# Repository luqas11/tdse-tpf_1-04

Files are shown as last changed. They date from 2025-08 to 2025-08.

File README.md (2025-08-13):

# Proyecto Final
Este proyecto es el diseño de software y hardware para un **sistema de control de una máquina expendedora de bebidas**, proyecto final de la materia Taller de Sistemas Embebidos de la FIUBA.

## Notas
Para depurar el proyecto, se deben realizar las siguientes configuraciones en el STM32CubeIDE:
1. Run -> Debug configurations -> Debugger -> Debug Probe -> ST-LINK (OpenOCD) -> Apply
2. Run -> Debug configurations -> Debugger -> Show generator options -> Reset Mode -> Software system reset -> Apply
3. Run -> Debug configurations -> Startup -> Initialization Commands -> Escribir `monitor arm semihosting enable` -> Apply

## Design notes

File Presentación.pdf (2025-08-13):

# Proyecto Final

MÁQUINA EXPENDEDORA DE BEBIDAS.

Taller de Sistemas Embebidos. Primer Cuatrimestre de 2025.

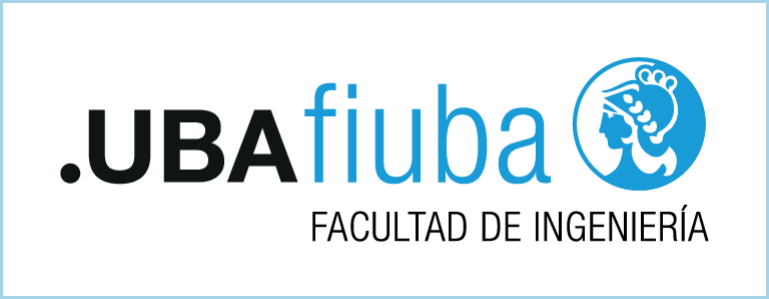
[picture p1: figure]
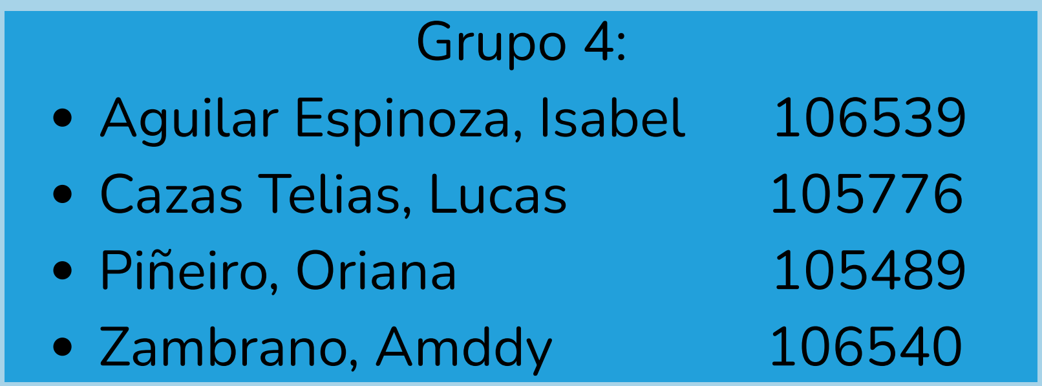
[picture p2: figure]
Grupo 4:; Aguilar Espinoza, Isabel; Cazas Telias, Lucas; Piñeiro, Oriana; Zambrano, Amddy

# Introducción al Proyecto

Este proyecto se centra en el diseño y la construcción de un prototipo para una máquina expendedora de bebidas. El sistema está gobernado por una placa de desarrollo NUCLEO-F103RB y cuenta con una interfaz de usuario que incluye una pantalla LCD y botones para la selección e interacción.

## Características Principales:

Controlador: Placa NUCLEO-F103RB
Interfaz de Usuario: Pantalla LCD y botones.
Funcionalidades:
Modo Cliente: Selección de 4 bebidas.
Modo Configuración: Gestión de precios y stock.

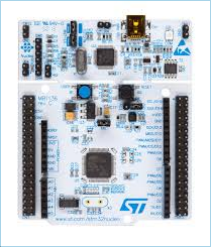
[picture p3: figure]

Detección de monedas (simulada mediante un botón). Indicador de estado a través de un LED RGB.

# Arquitectura del Hardware

La placa NUCLEO-F103RB funciona como la unidad de control principal del sistema, gestionando la interconexión con los diversos componentes periféricos para la operación de la máquina expendedora.

## Componentes Claves:

Placa NUCLEO-F103RB: Encargado de procesar la lógica de la máquina.
Display LCD (16x2): Proporciona información al usuario, como la bebida seleccionada, el precio y los estados de la máquina.

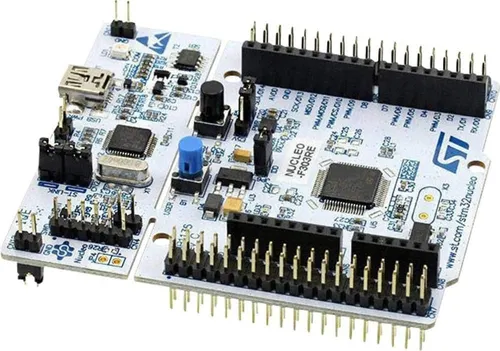
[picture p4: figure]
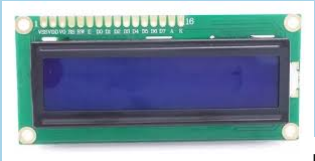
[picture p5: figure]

LED RGB: Ofrece una indicación visual del estado del sistema (Entrega de la bebida seleccionada).
Botones: Permiten la interacción del usuario (cliente y técnico) para navegar por los menús, seleccionar bebidas y confirmar acciones.
Sensor de Temperatura (LM35): Monitorea la temperatura de refrigeración de las bebidas. En caso de que la temperatura no sea la adecuada, el sistema entra en modo error.
Sensor de Monedas: Se simula a través de un botón (COIN) para registrar el ingreso de crédito.

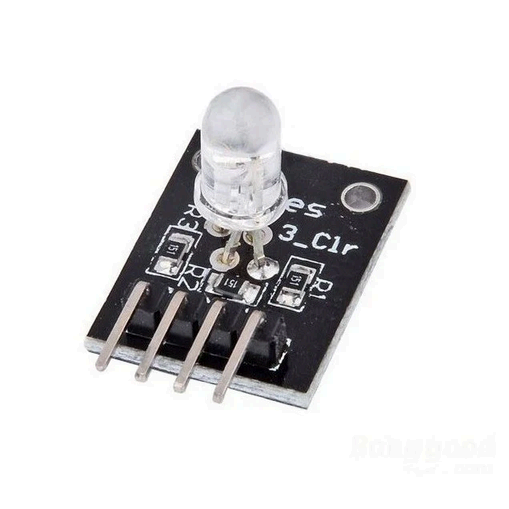
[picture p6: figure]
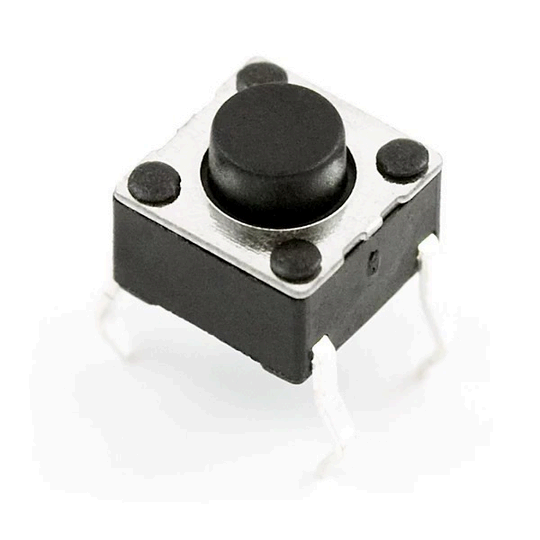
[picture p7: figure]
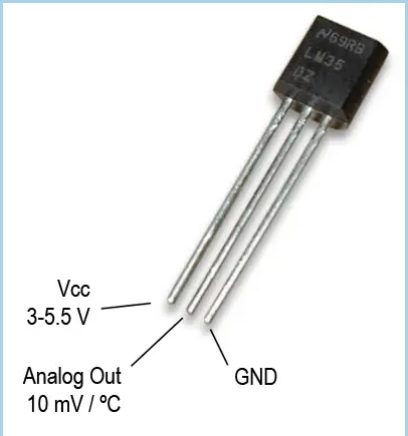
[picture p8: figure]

# Diagrama de Conexiones (Pinout)

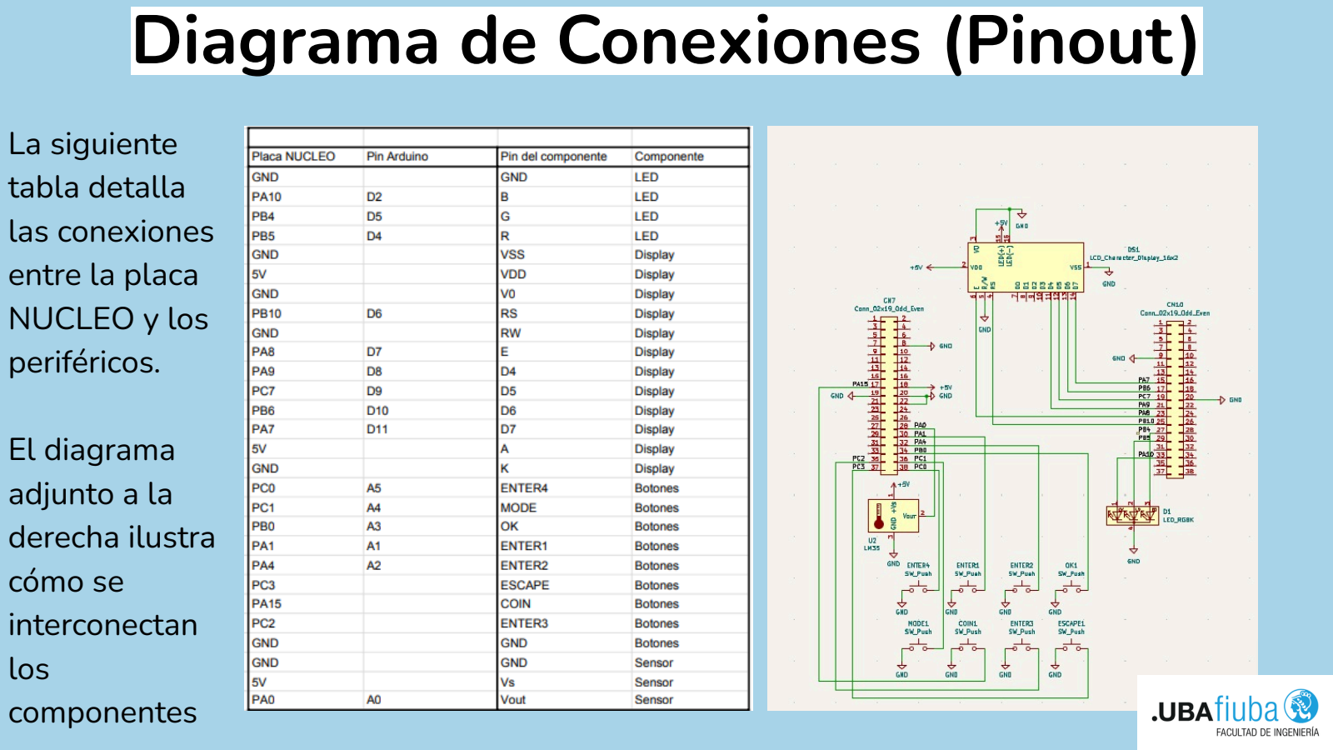
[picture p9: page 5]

La siguiente
tabla detalla
las conexiones
entre la placa
NUCLEO y los
periféricos.

El diagrama
adjunto a la
derecha ilustra
cómo se
interconectan
los
componentes

# Diseño del Software: Máquina de Estados

El firmware de la máquina expendedora se ha estructurado en torno a un modelo de máquina de estados para gestionar la interacción con el usuario de una manera ordenada y predecible. Se utilizó Itemis CREATE para simular el Diagrama de Estados.

## Menú de Usuario

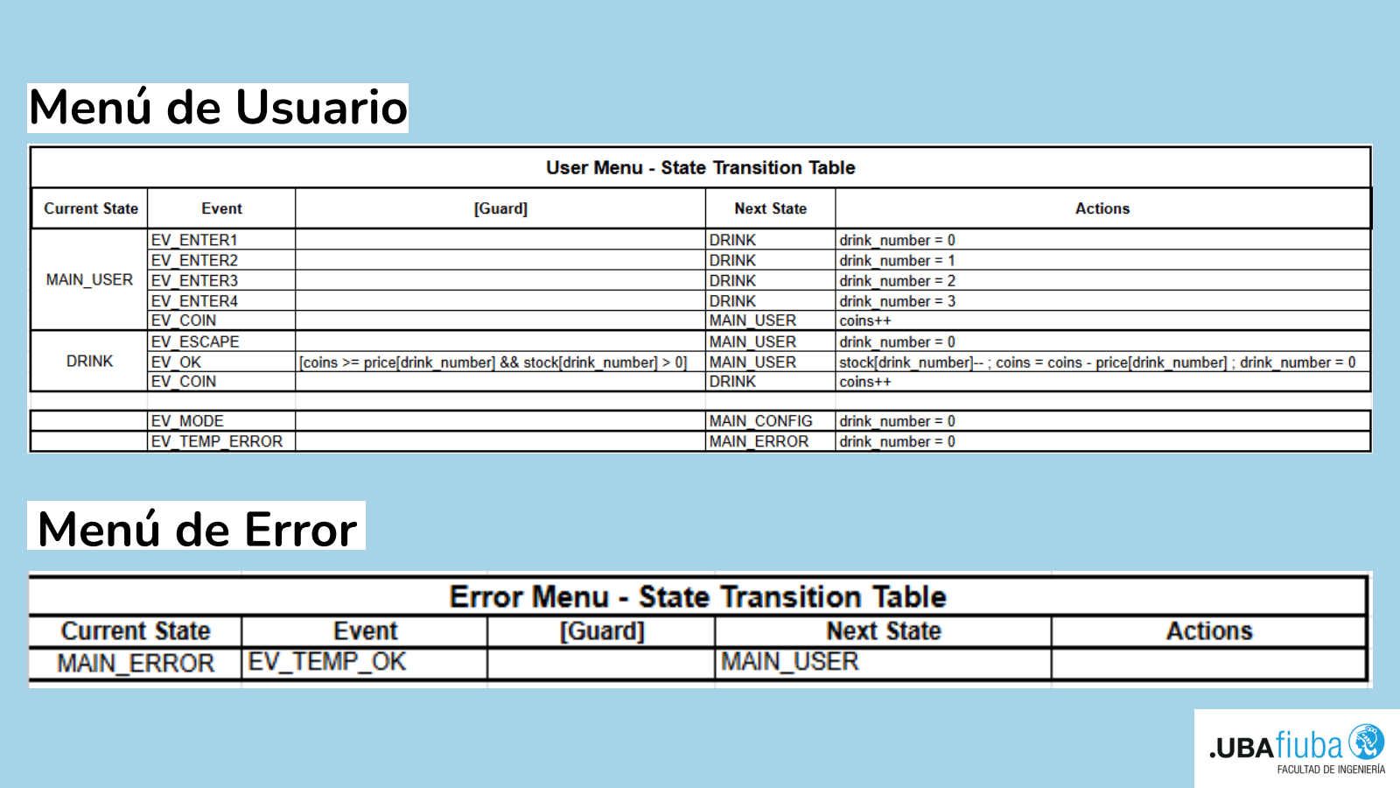
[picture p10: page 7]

## Menú de Error

## Menú de configuración

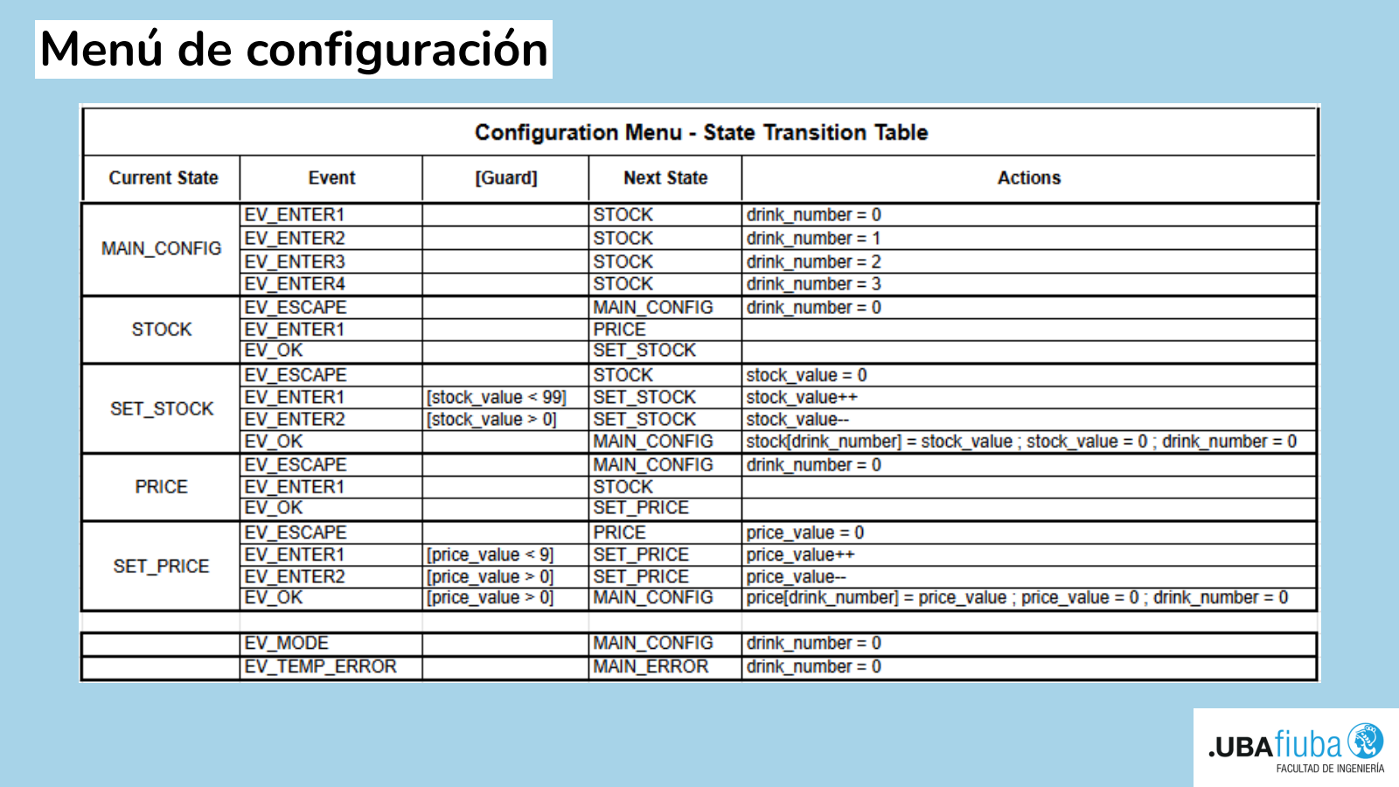
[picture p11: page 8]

# Diagrama de Estados Menú del usuario

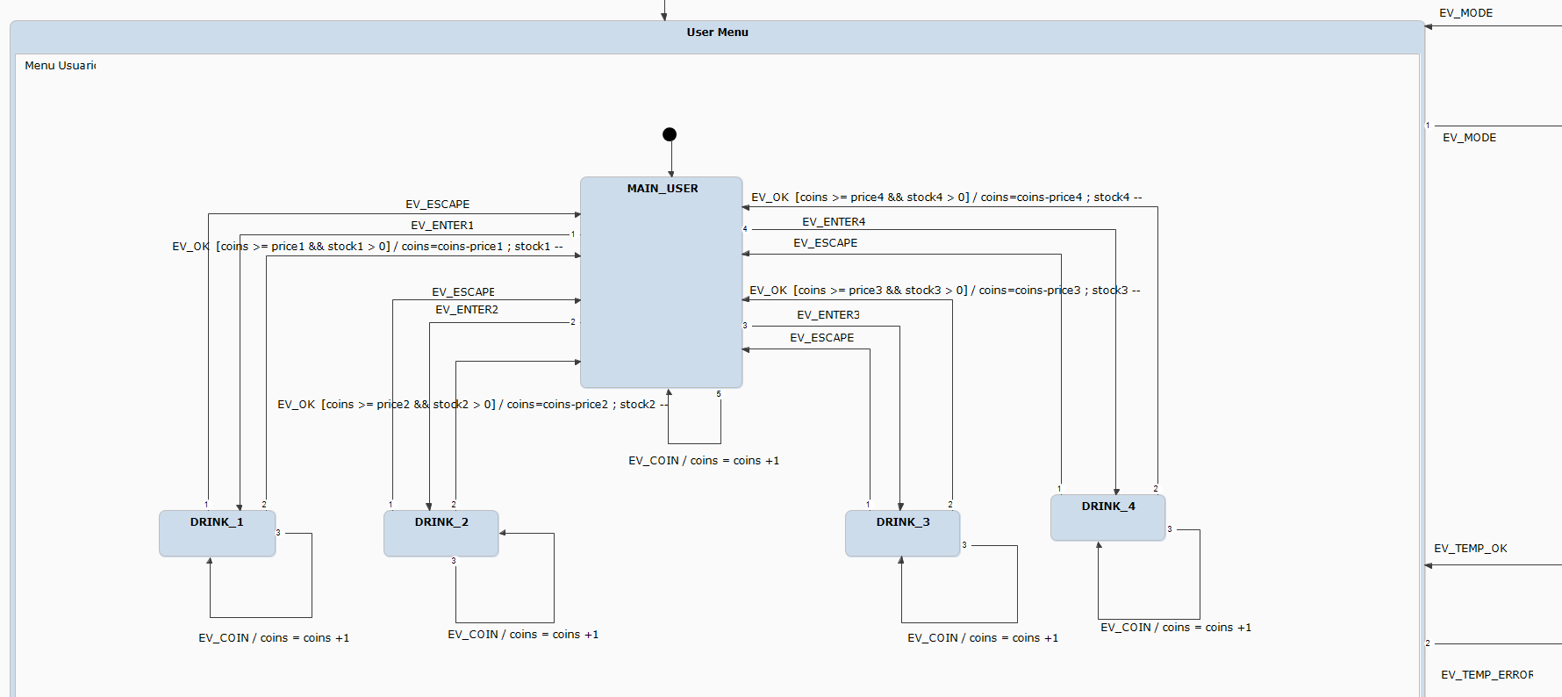
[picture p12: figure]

# Diagrama de Estados Menú del Técnico

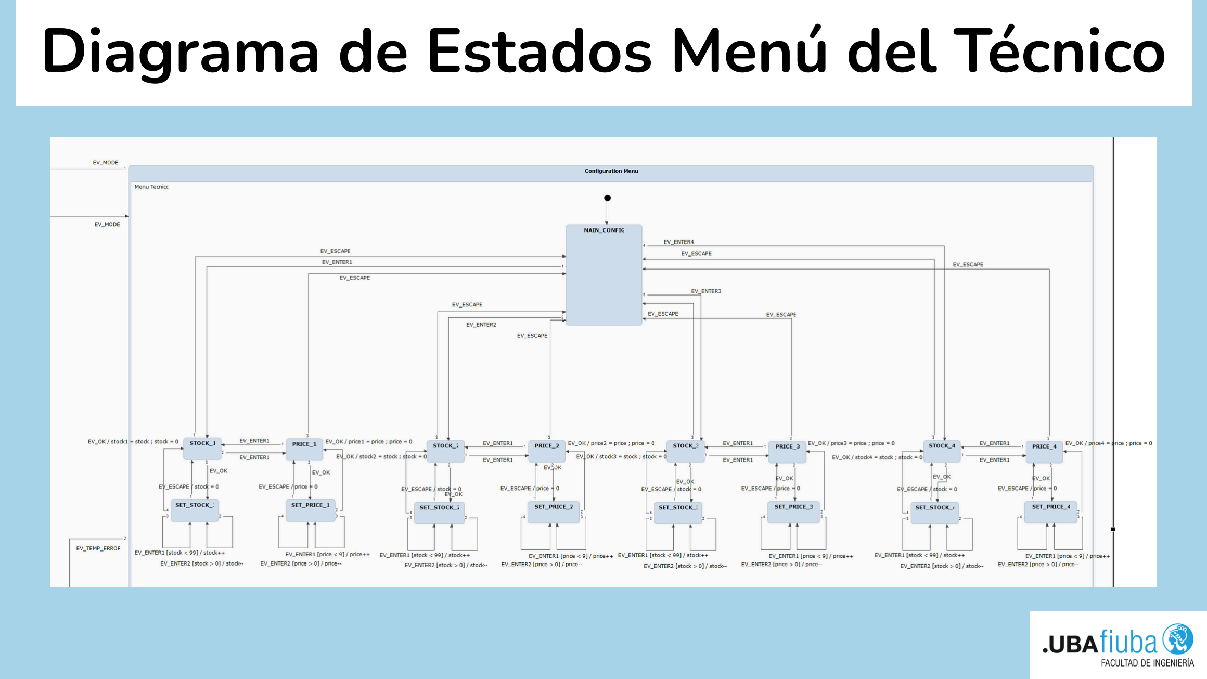
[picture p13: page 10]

# Diagrama del Estado de error

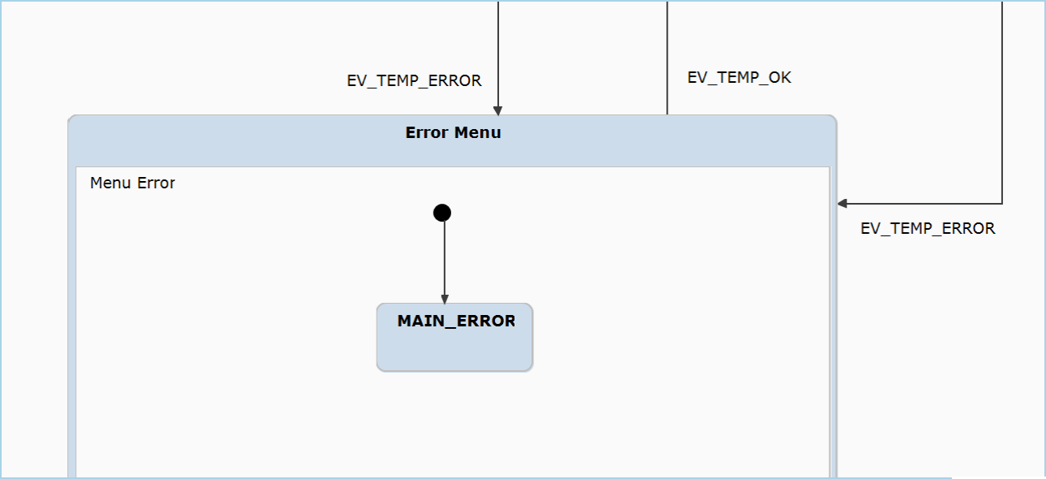
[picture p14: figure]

## Estados Principales del Menú de Usuario:

MAIN_USER: Estado de reposo donde el usuario puede iniciar una selección o insertar monedas.

DRINK: Estado que se activa tras la selección de una bebida. Aquí el usuario puede confirmar la compra o añadir más crédito.

MAIN_CONFIG: Un estado previsto para la configuración de la máquina, como ajustar precios y el stock inicial.

MAIN_ERROR: Un estado de seguridad para gestionar posibles fallos, como un error de temperatura.
Las funciones de incrementar y decrementar el stock y los precios se consolidaron en los botones ENTER1 y ENTER2 respectivamente.

# Flujo de Interacción del Usuario

Selección de Bebida: Desde el estado MAIN_USER, al presionar uno de los botones ENTER (1-4), el sistema transita al estado DRINK, asignando el número de bebida correspondiente.
Ingreso de Crédito: En cualquier momento, el evento EV_COIN incrementa el contador de monedas del usuario.
Confirmación de Compra: En el estado DRINK, al presionar OK (EV_OK), el sistema ejecuta una guarda de validación. Si el crédito es suficiente (coins >= price) y hay existencias (stock > 0), la compra se procesa.
Despacho y Actualización: Tras una compra exitosa, el stock de la bebida se decrementa, el crédito se descuenta y el sistema regresa a MAIN_USER. La luz LED se enciende de un color diferente para la representación de una bebida (bebida 1: verde, bebida 2: rojo, bebida 3, azul, bebida 4: celeste).
Cancelación: El evento EV_ESCAPE permite al usuario cancelar la operación en cualquier momento y volver al menú principal.

# Entorno de Desarrollo y Diseño de PCB

Entorno de Desarrollo: El software embebido fue desarrollado en el STM32CubeIDE.

Diseño de PCB con KiCad: El diseño del circuito impreso (PCB) se realizó con el software KiCad. Se definieron reglas de diseño específicas, como un ancho de pista mínimo de 1.0 mm para asegurar la integridad y la calidad de la placa de circuito impreso. En base a este diseño se soldaron las pistas y los pines para conectar los componentes en la placa de desarrollo experimental.

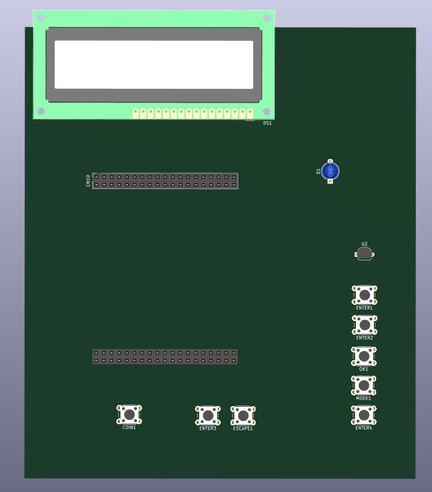
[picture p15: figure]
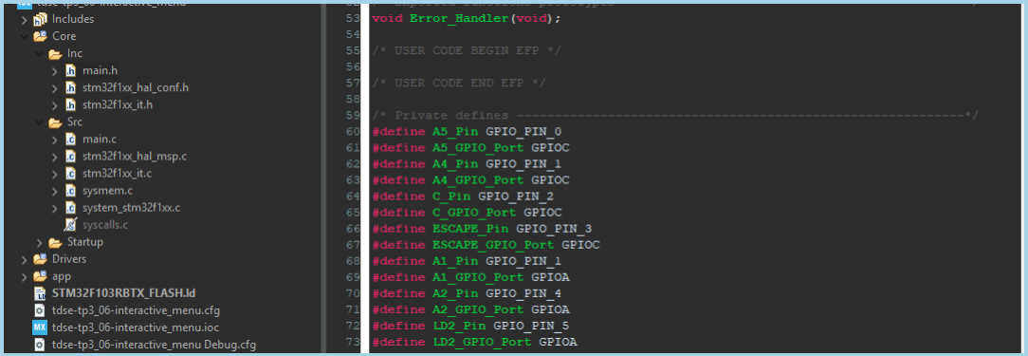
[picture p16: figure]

# Análisis de Consumo Energético

Se realizó un análisis del consumo de corriente de los componentes clave para evaluar la demanda energética del sistema.

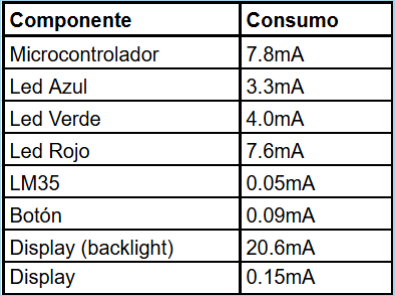
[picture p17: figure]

# Conclusión

La culminación de este proyecto es un prototipo funcional de una máquina expendedora de bebidas que demuestra una exitosa integración entre el hardware y el software.
La lógica de control se implementó a través de una máquina de estados que gestiona los modos de usuario, la selección de bebidas y la validación de compra. A nivel de hardware, se realizó un diseño de circuito impreso en KiCad con parámetros definidos, como un ancho de pista mínimo de 1.0 mm, lo que asegura la fiabilidad de las conexiones. Este enfoque integral, que abarca desde el consumo energético de cada componente hasta las conexiones específicas del microcontrolador, establece una base de ingeniería sólida para el futuro desarrollo y la producción de una versión comercial.

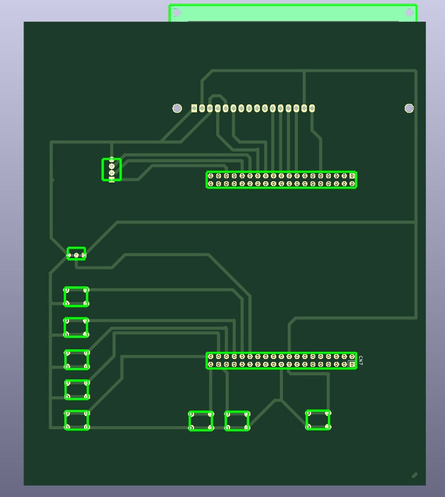
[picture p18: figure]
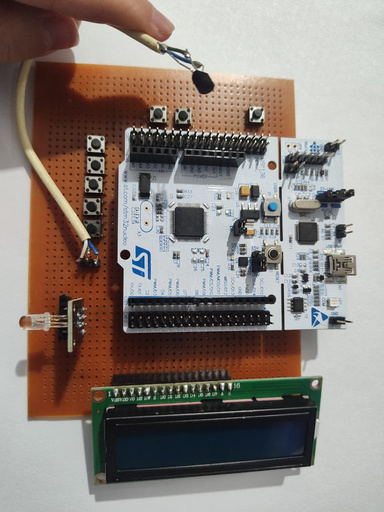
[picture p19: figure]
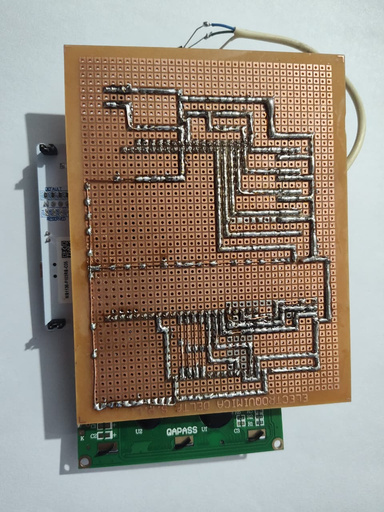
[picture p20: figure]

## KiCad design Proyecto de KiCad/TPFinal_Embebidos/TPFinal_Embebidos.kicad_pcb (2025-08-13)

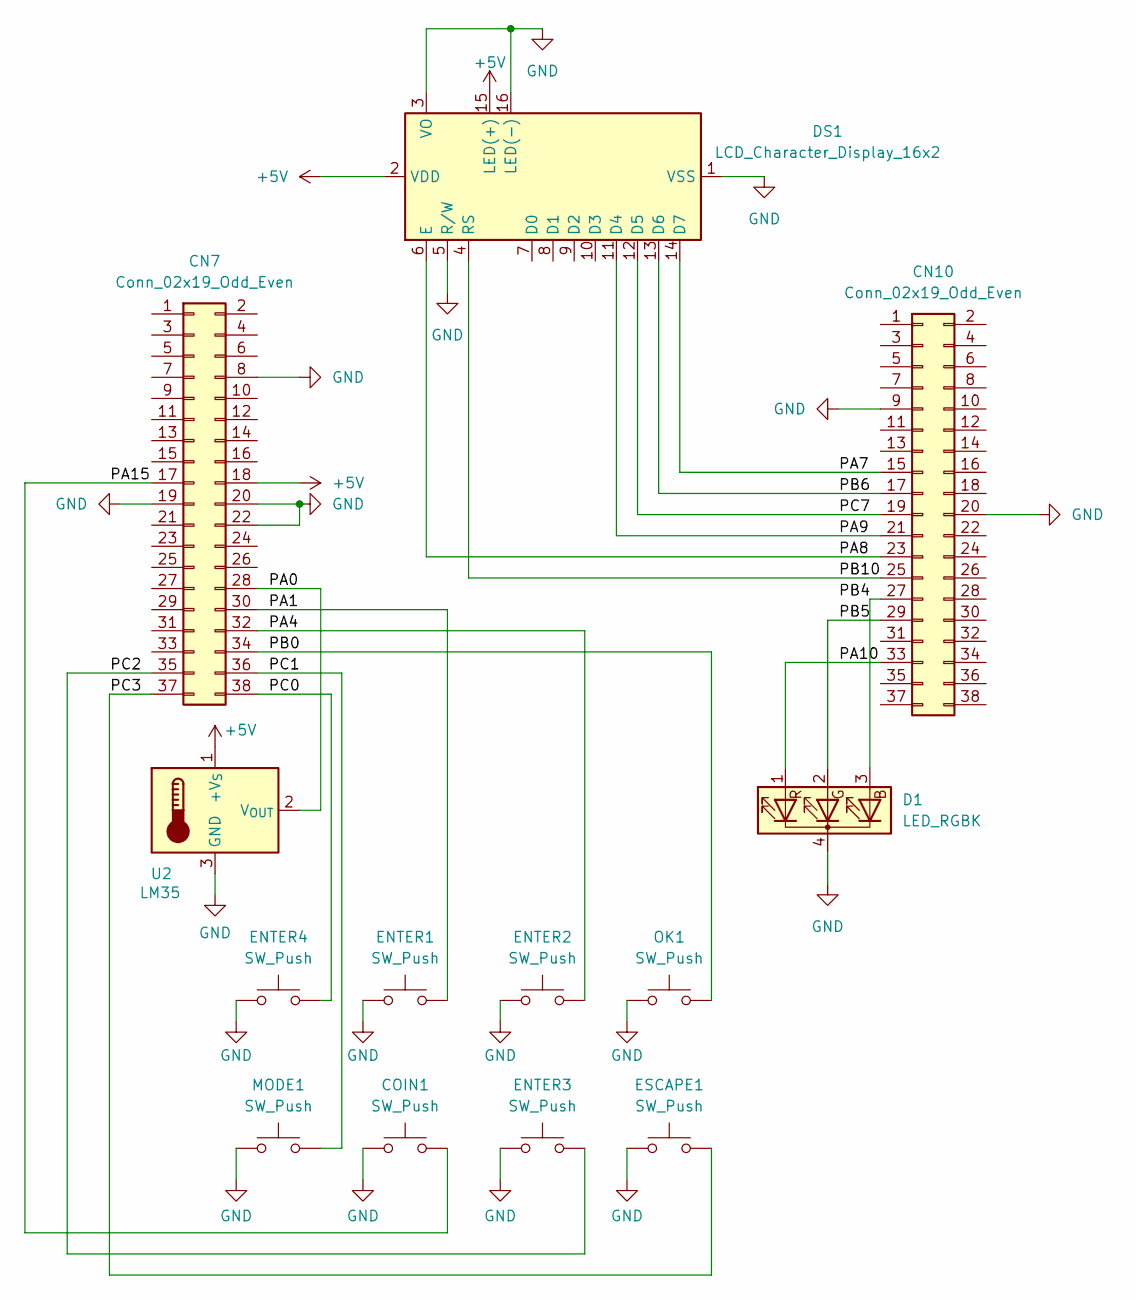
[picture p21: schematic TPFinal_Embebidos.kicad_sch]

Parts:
CN7, CN10: Conn_02x19_Odd_Even; PinSocket_2x19_P2.54mm_Vertical
COIN1: SW_Push; SW_PUSH_6mm_H7.3mm
D1: LED_RGBK; LED_D5.0mm-4_RGB_Wide_Pins
DS1: LCD_Character_Display_16x2; WC1602A
ENTER1, ENTER2, ENTER3, ENTER4: SW_Push; SW_PUSH_6mm_H7.3mm
ESCAPE1: SW_Push; SW_PUSH_6mm_H7.3mm
MODE1: SW_Push; SW_PUSH_6mm_H7.3mm
OK1: SW_Push; SW_PUSH_6mm_H7.3mm
U2: LM35; TO-92_Inline_Wide

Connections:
+5V: CN7.18, DS1.2 (VDD), DS1.15 (LED(+)), U2.1 (+V_{S})
/PA0: CN7.28, U2.2 (V_{OUT})
/PA1: CN7.30, ENTER1.2
/PA4: CN7.32, ENTER2.2
/PA7: CN10.15, DS1.14 (D7)
/PA8: CN10.23, DS1.6 (E)
/PA9: CN10.21, DS1.11 (D4)
/PA10: CN10.33, D1.1 (RA)
/PA15: CN7.17, COIN1.2
/PB0: CN7.34, OK1.2
/PB5: CN10.29, D1.2 (GA)
/PB6: CN10.17, DS1.13 (D6)
/PB10: CN10.25, DS1.4 (RS)
/PC0: CN7.38, ENTER4.2
/PC1: CN7.36, MODE1.2
/PC2: CN7.35, ENTER3.2
/PC3: CN7.37, ESCAPE1.2
/PC7: CN10.19, DS1.12 (D5)
GND: CN7.8, CN7.19, CN7.20, CN7.22, CN10.9, CN10.20, COIN1.1, D1.4 (K), DS1.1 (VSS), DS1.3 (VO), DS1.5 (R/W), DS1.16 (LED(-)), ENTER1.1, ENTER2.1, ENTER3.1, ENTER4.1, ESCAPE1.1, MODE1.1, OK1.1, U2.3 (GND)
unnamed: CN10.27, D1.3 (BA)

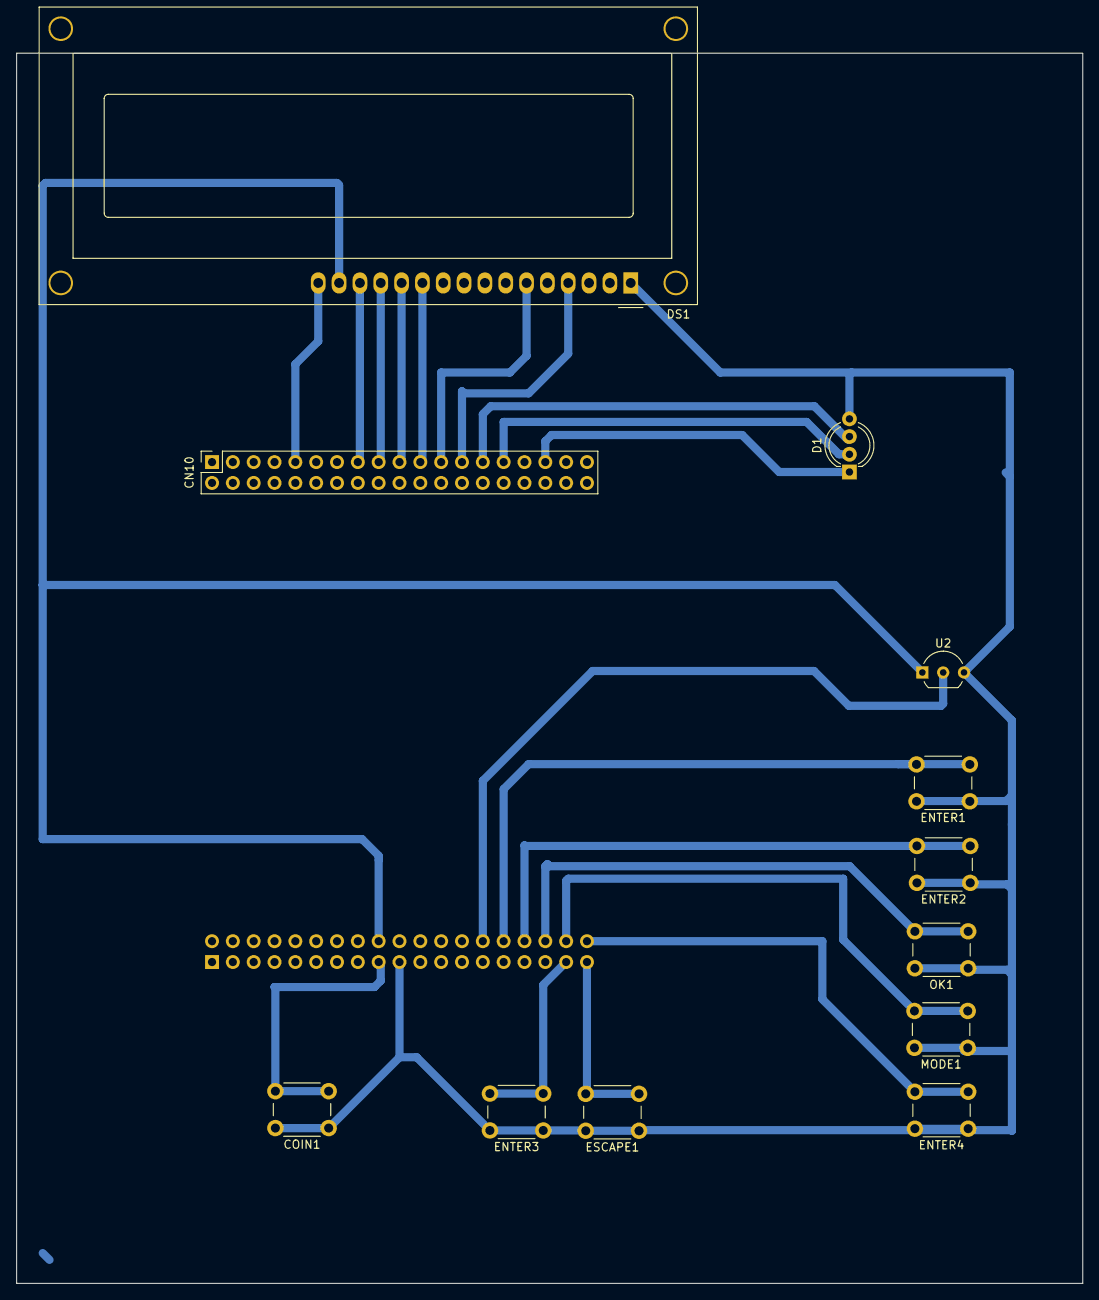
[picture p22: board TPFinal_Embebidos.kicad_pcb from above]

Board: 2 copper layers, 130.0 x 150.0 mm, 13 parts (1 on the bottom side), 20 nets.

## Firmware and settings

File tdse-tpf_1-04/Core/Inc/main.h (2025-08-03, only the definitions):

#define A5_Pin GPIO_PIN_0
#define A5_GPIO_Port GPIOC
#define A4_Pin GPIO_PIN_1
#define A4_GPIO_Port GPIOC
#define C_Pin GPIO_PIN_2
#define C_GPIO_Port GPIOC
#define ESCAPE_Pin GPIO_PIN_3
#define ESCAPE_GPIO_Port GPIOC
#define A1_Pin GPIO_PIN_1
#define A1_GPIO_Port GPIOA
#define A2_Pin GPIO_PIN_4
#define A2_GPIO_Port GPIOA
#define LD2_Pin GPIO_PIN_5
#define LD2_GPIO_Port GPIOA
#define D11_Pin GPIO_PIN_7
#define D11_GPIO_Port GPIOA
#define A3_Pin GPIO_PIN_0
#define A3_GPIO_Port GPIOB
#define D6_Pin GPIO_PIN_10
#define D6_GPIO_Port GPIOB
#define D9_Pin GPIO_PIN_7
#define D9_GPIO_Port GPIOC
#define D7_Pin GPIO_PIN_8
#define D7_GPIO_Port GPIOA
#define D8_Pin GPIO_PIN_9
#define D8_GPIO_Port GPIOA
#define D2_Pin GPIO_PIN_10
#define D2_GPIO_Port GPIOA
#define TMS_Pin GPIO_PIN_13
#define TMS_GPIO_Port GPIOA
#define TCK_Pin GPIO_PIN_14
#define TCK_GPIO_Port GPIOA
#define COIN_Pin GPIO_PIN_15
#define COIN_GPIO_Port GPIOA
#define SWO_Pin GPIO_PIN_3
#define SWO_GPIO_Port GPIOB
#define D5_Pin GPIO_PIN_4
#define D5_GPIO_Port GPIOB
#define D4_Pin GPIO_PIN_5
#define D4_GPIO_Port GPIOB
#define D10_Pin GPIO_PIN_6
#define D10_GPIO_Port GPIOB

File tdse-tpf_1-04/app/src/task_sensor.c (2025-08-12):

/*
 * Copyright (c) 2023 Juan Manuel Cruz <jcruz@fi.uba.ar> <jcruz@frba.utn.edu.ar>.
 * All rights reserved.
 *
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
 * 1. Redistributions of source code must retain the above copyright
 *    notice, this list of conditions and the following disclaimer.
 *
 * 2. Redistributions in binary form must reproduce the above copyright
 *    notice, this list of conditions and the following disclaimer in the
 *    documentation and/or other materials provided with the distribution.
 *
 * 3. Neither the name of the copyright holder nor the names of its
 *    contributors may be used to endorse or promote products derived from
 *    this software without specific prior written permission.
 *
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
 *
 * @file   : task_sensor.c
 * @date   : Set 26, 2023
 * @author : Juan Manuel Cruz <jcruz@fi.uba.ar> <jcruz@frba.utn.edu.ar>
 * @version	v1.0.0
 */

/********************** inclusions *******************************************/
/* Project includes. */
#include "main.h"

/* Demo includes. */
#include "logger.h"
#include "dwt.h"

/* Application & Tasks includes. */
#include "board.h"
#include "app.h"
#include "task_sensor_attribute.h"
#include "task_menu_attribute.h"
#include "task_menu_interface.h"

/********************** macros and definitions *******************************/
#define G_TASK_SEN_CNT_INIT			0ul
#define G_TASK_SEN_TICK_CNT_INI		0ul

#define DEL_BTN_XX_MIN				0ul
#define DEL_BTN_XX_MED				25ul
#define DEL_BTN_XX_MAX				50ul

#define DEL_ADC_XX_MIN				0ul
#define DEL_ADC_XX_MAX				500ul

#define TEMP_THRESHOLD				600

/********************** internal data declaration ****************************/
const task_sensor_cfg_t task_sensor_cfg_list[] = {
	{ID_BTN_ENTER1,  BTN_ENTER1_PORT,  BTN_ENTER1_PIN,  BTN_ENTER1_PRESSED, DEL_BTN_XX_MAX,
	 EV_MEN_ENTER1_IDLE,  EV_MEN_ENTER1_ACTIVE},
	{ID_BTN_ENTER2,  BTN_ENTER2_PORT,  BTN_ENTER2_PIN,  BTN_ENTER2_PRESSED, DEL_BTN_XX_MAX,
	 EV_MEN_ENTER2_IDLE,  EV_MEN_ENTER2_ACTIVE},
	{ID_BTN_ENTER3,  BTN_ENTER3_PORT,  BTN_ENTER3_PIN,  BTN_ENTER3_PRESSED, DEL_BTN_XX_MAX,
	 EV_MEN_ENTER3_IDLE,  EV_MEN_ENTER3_ACTIVE},
	{ID_BTN_ENTER4,  BTN_ENTER4_PORT,  BTN_ENTER4_PIN,  BTN_ENTER4_PRESSED, DEL_BTN_XX_MAX,
	 EV_MEN_ENTER4_IDLE,  EV_MEN_ENTER4_ACTIVE},
	{ID_BTN_MODE,  BTN_MODE_PORT,  BTN_MODE_PIN,  BTN_MODE_PRESSED, DEL_BTN_XX_MAX,
	 EV_MEN_MODE_IDLE,  EV_MEN_MODE_ACTIVE},
	{ID_BTN_OK,  BTN_OK_PORT,  BTN_OK_PIN,  BTN_OK_PRESSED, DEL_BTN_XX_MAX,
	 EV_MEN_OK_IDLE,  EV_MEN_OK_ACTIVE},
	{ID_BTN_ESCAPE,  BTN_ESCAPE_PORT,  BTN_ESCAPE_PIN,  BTN_ESCAPE_PRESSED, DEL_BTN_XX_MAX,
	 EV_MEN_ESCAPE_IDLE,  EV_MEN_ESCAPE_ACTIVE},
	{ID_BTN_COIN,  BTN_COIN_PORT,  BTN_COIN_PIN,  BTN_COIN_PRESSED, DEL_BTN_XX_MAX,
	 EV_MEN_COIN_IDLE,  EV_MEN_COIN_ACTIVE},
	{ID_ADC_TEMP,  0,  0,  0, DEL_BTN_XX_MAX,
	 EV_MEN_TEMP_IDLE,  EV_MEN_TEMP_ACTIVE, true, DEL_ADC_XX_MAX},
};

#define SENSOR_CFG_QTY	(sizeof(task_sensor_cfg_list)/sizeof(task_sensor_cfg_t))

task_sensor_dta_t task_sensor_dta_list[] = {
	{DEL_BTN_XX_MIN, ST_BTN_XX_UP, EV_BTN_XX_UP},
	{DEL_BTN_XX_MIN, ST_BTN_XX_UP, EV_BTN_XX_UP},
	{DEL_BTN_XX_MIN, ST_BTN_XX_UP, EV_BTN_XX_UP},
	{DEL_BTN_XX_MIN, ST_BTN_XX_UP, EV_BTN_XX_UP},
	{DEL_BTN_XX_MIN, ST_BTN_XX_UP, EV_BTN_XX_UP},
	{DEL_BTN_XX_MIN, ST_BTN_XX_UP, EV_BTN_XX_UP},
	{DEL_BTN_XX_MIN, ST_BTN_XX_UP, EV_BTN_XX_UP},
	{DEL_BTN_XX_MIN, ST_BTN_XX_UP, EV_BTN_XX_UP},
	{DEL_BTN_XX_MIN, ST_BTN_XX_UP, EV_BTN_XX_UP}
};

#define SENSOR_DTA_QTY	(sizeof(task_sensor_dta_list)/sizeof(task_sensor_dta_t))

extern ADC_HandleTypeDef hadc1;

/********************** internal functions declaration ***********************/

/********************** internal data definition *****************************/
const char *p_task_sensor 		= "Task Sensor (Sensor Statechart)";
const char *p_task_sensor_ 		= "Non-Blocking & Update By Time Code";

/********************** external data declaration ****************************/
uint32_t g_task_sensor_cnt;
volatile uint32_t g_task_sensor_tick_cnt;

/********************** external functions definition ************************/
HAL_StatusTypeDef ADC_Poll_Read(uint16_t *value) {
	HAL_StatusTypeDef res;

	res=HAL_ADC_Start(&hadc1);
	if ( HAL_OK==res ) {
		res=HAL_ADC_PollForConversion(&hadc1, 0);
		if ( HAL_OK==res ) {
			*value = HAL_ADC_GetValue(&hadc1);
		}
	}
	return res;
}

void task_sensor_init(void *parameters)
{
	uint32_t index;
	task_sensor_dta_t *p_task_sensor_dta;
	task_sensor_st_t state;
	task_sensor_ev_t event;

	/* Print out: Task Initialized */
	LOGGER_LOG("  %s is running - %s\r\n", GET_NAME(task_sensor_init), p_task_sensor);
	LOGGER_LOG("  %s is a %s\r\n", GET_NAME(task_sensor), p_task_sensor_);

	g_task_sensor_cnt = G_TASK_SEN_CNT_INIT;

	/* Print out: Task execution counter */
	LOGGER_LOG("   %s = %lu\r\n", GET_NAME(g_task_sensor_cnt), g_task_sensor_cnt);

	for (index = 0; SENSOR_DTA_QTY > index; index++)
	{
		/* Update Task Sensor Data Pointer */
		p_task_sensor_dta = &task_sensor_dta_list[index];

		/* Print out: Index & Task execution FSM */
		LOGGER_LOG("   %s = %lu", GET_NAME(index), index);

		state = p_task_sensor_dta->state;
		LOGGER_LOG("   %s = %lu", GET_NAME(state), (uint32_t)state);

		event = p_task_sensor_dta->event;
		LOGGER_LOG("   %s = %lu\r\n", GET_NAME(event), (uint32_t)event);
	}
	g_task_sensor_tick_cnt = G_TASK_SEN_TICK_CNT_INI;
}
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

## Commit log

2025-07-25 Add STM project
    [tdse-tp3_06-interactive_menu.cfg]
2025-07-28 Add buttons inputs configurations
    [tdse-tp3_06-interactive_menu Debug.cfg]
2025-07-28 Add LED and display pin configuration
2025-07-29 Add temperature sensor reading
2025-08-03 Fix stock and price limits
    [task_menu.c]
2025-08-03 Fix flash value saving
    [task_menu.c]
2025-08-03 Change pins to simplify PCB design
2025-08-12 Rename project
    [tdse-tp3_06-interactive_menu.cfg, tdse-tpf_1-04.cfg]
2025-08-13 Add project documentation
    [Conexión de pines.xlsx, Consumos de componentes.xlsx, TPFinal_Embebidos.kicad_pcb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]
2025-08-13 Add gitignore for KiCad project

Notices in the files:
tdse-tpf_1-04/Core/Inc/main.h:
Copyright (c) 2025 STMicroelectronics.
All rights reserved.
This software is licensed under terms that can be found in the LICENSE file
